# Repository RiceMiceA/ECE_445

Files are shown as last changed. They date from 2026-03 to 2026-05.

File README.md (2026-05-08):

# NuChef<sup>TM</sup> - AI Culinary Assistant

## Table of Contents
1. [Final Product](#1-final-product)
    - [Photos](#photos)
    - [YouTube Demo](#youtube-demo)
2. [How to use our repo?](#2-how-to-use-our-repo)
    - [Init](#21-init)
    - [Managing the submodule Unity folder](#22-managing-the-submodule-unity-folder)
    - [Network Configuration](#3-network-configuration)
    - [Troubleshooting](#4-troubleshooting)
5. [Third-Party Libraries & Licenses](#5-third-party-libraries--licenses)

## 1. Final Product
### Photos
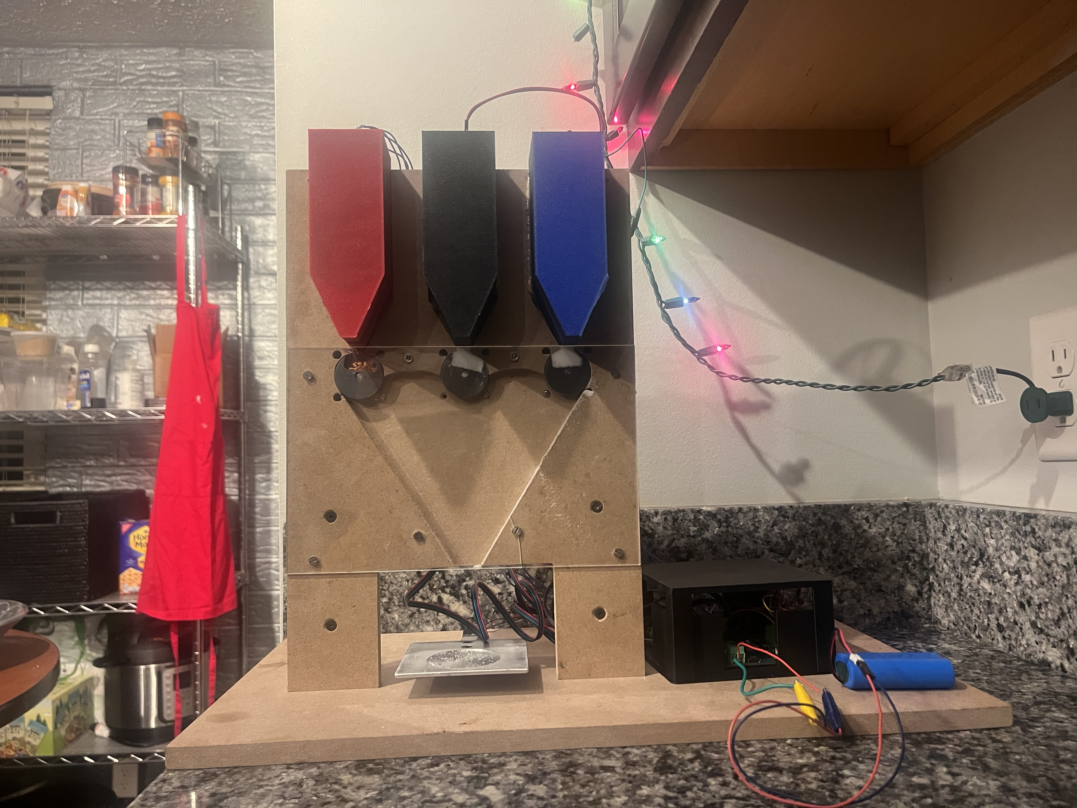
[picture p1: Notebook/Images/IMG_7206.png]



### YouTube Demo
NuChef Demo (https://www.youtube.com/watch?v=w1jBzbUWaAI)

## 2. How to use our repo?

### 2.1 Init
#### Freshly Clone 1st time
```bash
git clone --recurse-submodules <repo-url>
```

This does everything:
- clones the parent repo
- initializes submodules
- checks out the correct commits

#### Already cloned repo
```bash
git submodule update --init --recursive
```

### 2.2 Managing the submodule Unity folder
#### 2.2.1 Before Work/Update
#### In parent folder
```bash
git pull
git submodule update --init --recursive
```

#### 2.2.2 Post-work
```bash
cd path/to/submodule
git checkout main
git pull origin main
git add .
git commit -m "Update submodule"
git push origin main

cd /path/to/parent-repo
git add Software/src/Unity-PassthroughCameraApiSamples
git commit -m "Bump submodule"
git push origin main
```

### Verify Health
```bash
git submodule status
```

### Tip
```bash
git config --global submodule.recurse true
# if we wanna track the specific branch
git submodule set-branch --branch tony Software/src/Unity-PassthroughCameraApiSamples
git submodule update --remote
```

## 3. Network Configuration

### Kill previous run
```bash
kill $(lsof -t -i:8000) 
```

### Update IP Address before operation
```bash
Check the current ip address: 
```
When switching networks, update the backend IP (`192.168.x.x`) in these files:

| File | Line | Variable |
| --- | ---- | --- |
| [`Software/src/Unity-PassthroughCameraApiSamples/Assets/PassthroughCameraApiSamples/MultiObjectDetection/DetectionManager/Scripts/BackendClient.cs`](Software/src/Unity-PassthroughCameraApiSamples/Assets/PassthroughCameraApiSamples/MultiObjectDetection/DetectionManager/Scripts/BackendClient.cs#L19) | 19 | `m_baseUrl` |
| [`Software/src/web_app/main/script.js`](Software/src/web_app/main/script.js#L6) | 6 | `BACKEND_URL` |

> **Note:** The ESP32 now communicates via **BLE** (not WiFi), so it no longer needs an IP address or network config.

Then start the backend and BLE bridge:
```bash
# Terminal 1 — backend
cd Software/src/web_app
source .env   # loads OPENAI_API_KEY, OPENAI_MODEL, USE_LLM_PLANNER from .env file
uvicorn backend:app --host 0.0.0.0 --port 8000 --reload

# Terminal 2 — BLE bridge (connects to ESP32 over Bluetooth, forwards to backend)
pip install bleak httpx   # first time only
python ble_bridge.py
```

## 4. Troubleshooting

### Upload new ESP32 file
```bash
~/.platformio/penv/bin/pio run 2>&1 | tail -20
```

### ESP32 BLE not broadcasting / bridge can't find device
1. **Press the physical RESET button** on the ESP32-S3 board. It will re-advertise as `NuChef-Dispenser` within a few seconds.
2. If the bridge still can't find it, kill and restart `ble_bridge.py`. Linux's BlueZ stack sometimes caches stale BLE data.
3. As a last resort, power-cycle the ESP32 (unplug & replug USB).

### Serial port changed (`/dev/ttyACM0` ↔ `/dev/ttyACM1`)
After a reset or replug the port may shift. Check with:
```bash
ls /dev/ttyACM*
```
Then update `upload_port` and `monitor_port` in `Software/src/esp_driver/platformio.ini` if you need to re-flash.

### Permission denied on `/dev/ttyACM*`
```bash
sudo usermod -aG dialout $USER
# then log out & back in (or reboot) for the group to take effect
```

### Bridge connects but dispense doesn't trigger from the UI
- Make sure the backend (`uvicorn`) **and** `ble_bridge.py` are both running.
- Verify `BACKEND_URL` in `script.js` is `window.location.origin` (not a hardcoded IP).
- Check the bridge terminal for `BLE CMD →` and `write OK` logs when you click **Dispense**.

### Quick sanity check (motor spin from CLI)
```bash
# Direct BLE test — bypasses the backend entirely
python3 -c "
import asyncio
from bleak import BleakClient, BleakScanner
SVC  = '4e7a9b1c-d203-4e2a-b8f1-67c1d9e3f5a0'
CMD  = '4e7a9b1c-d203-4e2a-b8f1-67c1d9e3f5a1'
async def test():
    dev = await BleakScanner.find_device_by_name('NuChef-Dispenser', timeout=10)
    async with BleakClient(dev) as c:
        await c.write_gatt_char(CMD, b'spin', response=True)
        await asyncio.sleep(5)
        await c.write_gatt_char(CMD, b'stop', response=True)
asyncio.run(test())
"
```

## 5. Third-Party Libraries & Licenses

### Unity Utility Packages (MIT)
- **Repository:** https://github.com/meta-quest/Unity-UtilityPackages
- **Author:** Meta Platforms, Inc. and affiliates
- **License:** MIT License

> Meta Quest, "Unity-UtilityPackages," GitHub. [Online]. Available: https://github.com/meta-quest/Unity-UtilityPackages. [Accessed: May 7, 2026].

MIT License attribution:
```
Unity Utility Packages
Copyright (c) Meta Platforms, Inc. and affiliates.
Licensed under the MIT License.
https://github.com/meta-quest/Unity-UtilityPackages
```

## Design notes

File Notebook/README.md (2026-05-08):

# General Information about our ECE445 NuChef AI Culinary Assistant

## Problem

The processed food industry has become increasingly toxic due to chemical flavor additives, which have been associated with a 12%–32% higher cancer risk. At the same time, getting into cooking can be intimidating for new chefs. As a result, students and working professionals may rely on convenient but unhealthy meals.

Most currently available smart-cooking tools do not provide a real-time experience that guides users through the complete process from raw ingredients to the finished dish. This makes it difficult for users to learn how to cook or even get started. It is also inefficient to design recipes that adapt to the ingredients the user already has available, since a prospective cook would otherwise need to manually catalog everything on hand.

This creates two main problems: users may waste food, and recipe creation remains an expert skill that is difficult to customize. Spices are especially difficult to measure and control in a dish, even though they are often the most important contributors to flavor. A healthy and delicious diet is important for productivity and long-term health, but it can be difficult to accomplish consistently.

## Solution

We propose an **AI-Nutritious Culinary Assistant** that recognizes available ingredients and generates a personalized recipe with interactive, step-by-step guidance.

The system uses the **Meta Quest 3** as the user interface and sensor front-end. The headset streams video and voice commands to an edge vision processor running an ingredient-recognition pipeline. In addition to vision, the device integrates an environmental sensor module that measures ingredient weight for portion verification.

The appliance also includes a circular seasoning dispenser driven by stepper motors for proportional seasoning action. This enables closed-loop “dispense to target grams” assistance during cooking. The spice containers also contain IR sensors, allowing users to view the percentage of each spice remaining and receive an alert when a spice is running low.

## Visual Aid

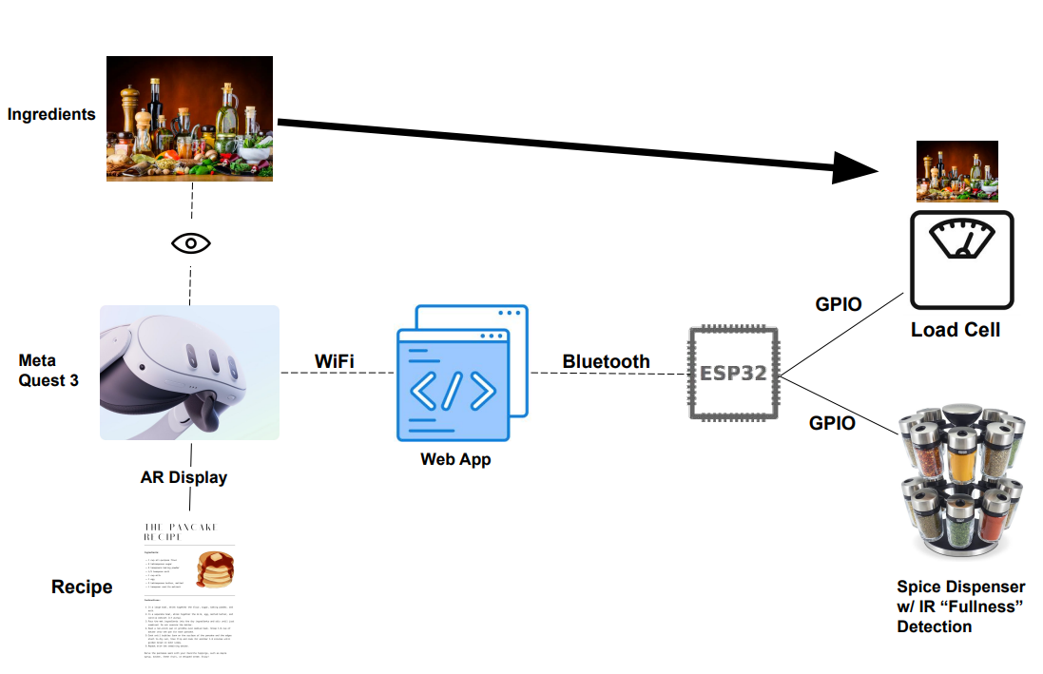
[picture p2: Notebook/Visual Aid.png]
High Level Abstraction of The Project Pipeline

**Figure 1. High-Level Abstraction of the Project Pipeline**

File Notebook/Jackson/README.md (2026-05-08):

# Engineering Logbook

---

## Date: 2/10/26

### Objective
Parts purchasing for our project

### Details
The first major milestone for our project is deciding on the parts to buy. After meeting with my group and discussing parts, we have landed on the following components:

- ESP-32 S3 WROOM
- 10g load cell with HX711 ADC module
- 17HE15-1504 stepper motors
- VL53L4CD IR ToF sensors

The PCB and battery components will be decided by Griffin, who has the most experience in PCB design.

In addition to ordering these components, we also need the Oculus headset borrowed from the library or from Professor Gruev’s lab to run our computer vision model.

---

## Date: 2/15/26 – 2/17/26

### Objective
Begin setting up environment and learning to use PlatformIO in preparation to begin coding ESP

### Details
Parts have arrived and we have given them to the woodshop with our general idea and concept of a design. Once they have finished the frame for the spice dispenser, I will be able to begin programming the motors.

Until then, I learned how to set up my PlatformIO environment in VSCode to be able to program the ESP. I originally looked at the Arduino IDE, but PlatformIO worked better with VSCode and members of my group had more knowledge using it.

I followed this tutorial to get my environment set up:

<https://randomnerdtutorials.com/vs-code-platformio-ide-esp32-esp8266-arduino/>

---

## Date: 3/2/26

### Objective
To get the motors connected to the ESP and ensure that they can spin and properly be controlled.

### Details
The main frame has returned from the supply shop and I am able to start work coding the motors and the sensors. The physical rotation of the motors is the most essential part of the project, so I am starting with this first.

We ordered a TB6612FNG motor driver breakout board to be able to easily control our stepper motors. We also have an older ESP-32 with breadboard pins that can be used and coded on the breadboard.

The motors were chosen due to their precision, as 200 steps result in one full rotation back to the starting position with generally specific accuracy.

The motors have four wires — `A+`, `A-`, `B+`, and `B-` — as seen in this datasheet:

<https://www.artme-3d.de/wp-content/uploads/2024/03/17HE15-1504S.pdf>

These four lines create two coils that allow for a spinning magnetic field when current is alternated through them in different directions. This is how we are able to get rotation in the stepper motors.

The DRV8833 is able to abstract this pin control into two pins, `IN1` and `IN2`, as seen in this datasheet:

<https://cdn.sparkfun.com/assets/0/1/b/b/3/TB6612FNG.pdf>

We are able to wire PWM and STBY to high and connect IN1 and IN2 to two GPIO pins on the ESP. We can then use the `AccelStepper` library to abstract the coding of these pins, though we understand that the current must alternate between the four pins to get a complete rotation.

The `AccelStepper` library examples can be found here:

<https://registry.platformio.org/libraries/waspinator/AccelStepper/examples>

Using a very basic example and modifying the code slightly, we can get one rotation on the motor each time we reset the ESP.

### Motor Test Code

```cpp
#include <Arduino.h>
#include <AccelStepper.h>
#include <BluetoothSerial.h>

BluetoothSerial SerialBT;

#define AIN1R 32
#define AIN2R 14
#define BIN1R 15
#define BIN2R 33

#define AIN1M 13
#define AIN2M 12
#define BIN1M 21
#define BIN2M 27

AccelStepper stepperRight(
    AccelStepper::FULL4WIRE,
    AIN1R, AIN2R, BIN1R, BIN2R
);

AccelStepper stepperMiddle(
    AccelStepper::FULL4WIRE,
    AIN1M, AIN2M, BIN1M, BIN2M
);

void spinMotor() {
    Serial.println("Spin command received");

    stepperRight.setCurrentPosition(0);
    stepperRight.moveTo(200);

    stepperMiddle.setCurrentPosition(0);
    stepperMiddle.moveTo(200);
}

void setup()
{
    Serial.begin(115200);

    // Stepper Motors Setup
    stepperMiddle.setMaxSpeed(800);
    stepperMiddle.setAcceleration(200);

    stepperRight.setMaxSpeed(800);
    stepperRight.setAcceleration(200);
}

void loop()
{
    stepperRight.run();
    stepperMiddle.run();
}
```

The general idea is to set the speed and acceleration of the motors and then tell them to move to position `200`. This means taking 200 steps, which for our motors is one full rotation.

There are only two motors set up here because the ESP we are using on the breadboard has limited GPIO. We will be testing this code at a future date.

---

## Date: 3/8/26

### Objective
To get the motors hooked up on the breadboard and use the ESP code to spin them on command.

### Details
We spent a lot of time on this day figuring out our communication with the ESP. We had to try multiple different cables until we found one that connected properly to my laptop.

We also found that, on this specific ESP that we were using for breadboard testing, certain pins that we thought were GPIO (like GPIO 4) caused problems when trying to program the ESP. It would not accept code over USB when those pins were used. These pins are likely related to resetting or idling the ESP, so we avoided them as much as possible.

We also realized that our TB6612FNG breakout board was made for general DC motors, not specifically stepper motors. It was still able to work, but stepper motors require a constant current to hold their position even when they are not actively rotating. This resulted in the chips getting very hot, so we could not leave them plugged in for too long.

Regardless, we were able to hook up the motors (two at a time because of limited GPIO on the ESP) and get them spinning.

We ordered a DRV8833 breakout board, which is the chip we are actually using on our PCB.

---

## Date: 3/9/26

### Objective
To get the project more prepared for the breadboard demo. This includes building a basic backend and frontend web app to allow the ESP to be controlled with the laptop.

### Details
The first step in setting up a web app was deciding how to build it. I decided to use FastAPI, as I do not need much bandwidth and it is easy to learn and test. I used this in conjunction with Uvicorn to get my server running.

I used GET and POST endpoints to allow me to see internal data as well as communicate with the ESP. The frontend/backend code can be seen in the GitHub commit labeled **WiFi capabilities**.

### ESP WiFi Connectivity Code

```cpp
WebServer server(80);

const char* ssid = "Triangle";
const char* password = "houserules";

void connectWiFi() {
  WiFi.begin(ssid, password);

  Serial.print("Connecting");

  while (WiFi.status() != WL_CONNECTED) {
    delay(500);
    Serial.print(".");
  }

  Serial.println("");
  Serial.print("ESP32 IP: ");
  Serial.println(WiFi.localIP());
}

void loop()
{
  stepper.run();
  server.handleClient();
  stepperMiddle.run();
}
```

With this code, the ESP is able to listen over WiFi. The web app can then call the `spinMotor()` function, which results in the spices being dispensed.

The SSID and password need to be changed based on location. In this example, it is configured for my home network.

This is a basic but effective way to communicate with the ESP over WiFi, and we confirmed it with a simple web app that can spin the motors.

### Demo API Endpoints

| Name | Type | Description |
|---|---|---|
| `new_recipe` | POST | Used by the Meta Quest 3 to send the selected recipe JSON |
| `status_update` | POST | Used by the ESP32 to send IR sensor and load cell data |
| `set_containers` | POST | Used by the frontend to allow user configuration of spices |
| `container_info` | GET | Used by the frontend to get IR sensor readings and load cell readings |

### Additional Backend GET Endpoints

| Name | Type | Description |
|---|---|---|
| `get_status` | GET | Returns the entire system state |
| `get_spices` | GET | Extracts and returns spices from the recipe JSON |
| `get_spice_dispense` | GET | Returns only spices currently in the dispenser |
| `get_container_info` | GET | Returns information on all containers |

### Basic Frontend

The frontend has some basic configuration that will later be used to connect the Oculus-to-ESP pipeline.

The “Spin Motor” button is the most important part of the demo because it shows we can communicate with the ESP over WiFi and control the motors remotely.

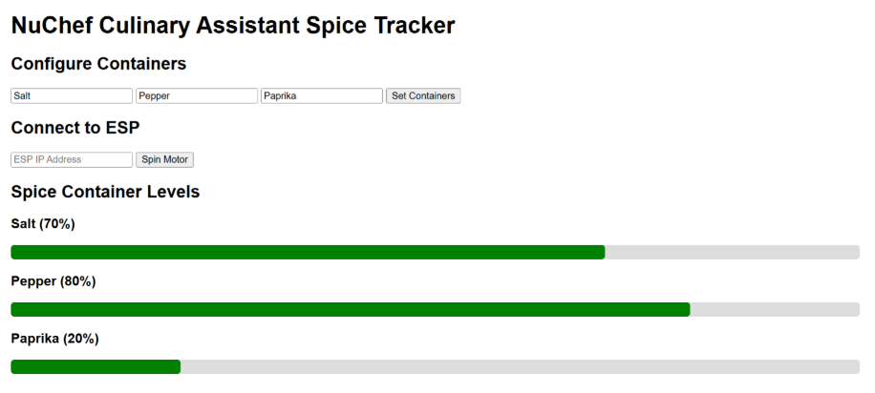
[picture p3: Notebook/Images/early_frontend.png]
Early Frontend


---

## Date: 3/10/26

### Objective
To debrief the breadboard demo and discuss next steps.

### Details
At the breadboard demo, the ESP was having trouble connecting to the university WiFi. It also was not able to connect to my phone’s hotspot.

We completed the demo using physical buttons to show some functionality, but afterward we discussed how to resolve the networking issues.

We decided to switch the ESP communication method from WiFi to Bluetooth. Griffin has worked with ESP Bluetooth before and said it is relatively simple and reliable. This will be our plan moving forward.

---

## Date: 3/28/26

### Objective
To hook up the load cell on the breadboard and get it running before our progress demo.

### Details
The load cell amplifier that came with the load cell was not working; it seemed like the chip was faulty. We ordered new HX711 breakout boards that would arrive before the progress demo, although we had to pay extra for shipping.

While waiting for the load cell amplifiers to arrive, I began work on the ESP code for them.

The load cell has four wires coming out of it. These wires allow us to provide an input voltage and read the voltage across the resistance terminals within the load cell.

When tension is applied to the cell, the resistance values change slightly, which causes a change in the internal voltage and allows us to read the weight. We can see this in the diagram below:

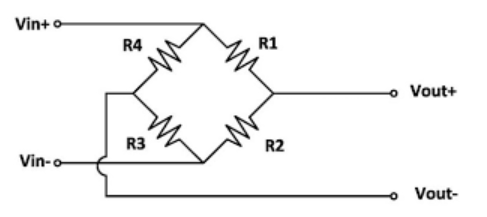
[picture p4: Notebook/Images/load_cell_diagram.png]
Load Cell Diagram


The HX711 amplifier allows us to amplify this small voltage change into an actual reading. We can then use GPIO and the HX711 library to get weight readings.

### HX711 Test Code

```cpp
#include "HX711.h"

// HX711 circuit wiring
const int LOADCELL_DOUT_PIN = 19;
const int LOADCELL_SCK_PIN = 20;

HX711 scale;

void setup() {
  Serial.begin(115200);

  pinMode(LOADCELL_SCK_PIN, OUTPUT);
  digitalWrite(LOADCELL_SCK_PIN, LOW);

  scale.begin(LOADCELL_DOUT_PIN, LOADCELL_SCK_PIN);
  scale.tare();
  scale.set_scale((1250.0)/1.0); //(reading)/actual weight
}

void loop() {

  if (scale.is_ready()) {
    float reading = scale.get_units(50);

    if(abs(reading) <= 0.05){
        reading = 0.00;
    }

    Serial.print("HX711 reading: ");
    Serial.println(reading);

  } else {
    Serial.println("HX711 not found.");
  }

  delay(1000);
}
```

---

## Date: 4/5/26

### Objective
To get the load cell working and hook up both the load cell and the motors for the progress demo.

### Details
The motors were simple to hook up because they used the same wiring as before, but now with our new breakout boards using the correct chips.

For the load cell and HX711, the wiring was also relatively straightforward:

- Red → `E+`
- Black → `E-`
- Green → `A+`
- White → `A-`

Once these are connected to the HX711, we only need the `DATA` and `SCK` lines connected to the ESP.

- `SCK` controls the clock
- `DATA` is used to read the data

Using the code written previously, I was able to display readings on the serial monitor.

I placed a 1-gram weight on the scale, which produced a reading of `1250`. I used this value to calibrate the scale so readings would display in grams.

There is some noise on the load cell because it is a low-weight cell and therefore very sensitive to changes in current or voltage, including outside electrical noise.

To combat this, we poll many data points and average them before displaying a reading. This increases the time between readings, but the results are much closer to the expected value.

Tony had made a slightly more advanced web application, so I gave him the load cell code so he could quickly implement it before the progress demo.

---

## Date: 4/7/26

### Objective
Progress demo and part pickup

### Details
Our progress demo went very well.

I also received many parts from Aniket that we had ordered through the ECEB supply shop. These included many of the top-solder components for our PCB, such as:

- Capacitors
- Resistors
- ESP module
- Voltage regulator

The remaining parts are still arriving in the mail, but we are close to having everything needed to begin soldering.

---

## Date: 4/12/26

### Objective
To begin soldering

### Details
I met with the rest of the group and we learned from a friend how to use solder paste and the heat plate at Triangle to top-solder our board.

Things were going well, but the voltage regulator chip developed a large solder bridge. While trying to separate the pins, one of them broke off.

We decided to order a replacement with express shipping and wait for it to arrive before continuing.

---

## Date: 4/22/26

### Objective
To get the IR sensors connected to the system and working.

### Details
Griffin soldered a small PCB with the IR sensor for testing on the breadboard.

The issue is that the IR sensor we bought has contacts underneath the chip, making it difficult to tell whether any contacts are disconnected or bridged.

I tried hooking the chip up to the ESP. On the VL53L4CD sensor, the two primary GPIO-related lines are:

- `SCL` — clock
- `SDA` — data

I could not get any readings from the sensor, even after trying different GPIO pins, wires, and configurations.

We decided to stop using the hand-soldered IR sensors and instead purchased VL53L4CD breakout boards.

---

## Date: 4/25/26

### Objective
To hook up the new IR sensor breakout boards and get readings displayed on the serial monitor.

### Details
I used the new breakout boards on the breadboard to try to get readings from the IR sensors.

The code I used was the basic continuous example from the Adafruit VL53L0X library:

<https://registry.platformio.org/libraries/adafruit/Adafruit_VL53L0X/examples/vl53l0x_continuous/vl53l0x_continuous.ino>

I spent a lot of time moving wires around because I believed there was a problem with my pin assignments or wiring.

While working, I accidentally pulled one of the wires out of the load cell. This took a long time to repair because the wires had been glued in place by the ECEB wood shop.

In the end, I did not make much progress, but we discovered that we had a spare load cell available and swapped it into the project.

---

## Date: 4/27/26

### Objective
To get all of the load cells hooked up and working.

### Details
We spent time hooking the IR sensors to the breadboard and ensuring that the pin assignments were correct.

Eventually, using the basic code, we were able to get readings that appeared accurate. However, when the sensors were placed on our spice containers, the calculated percentages based on distance readings were incorrect.

We were not able to fully resolve the issue before the demo, but we ensured the rest of the project was ready for the final demonstration.

Everything else was functioning properly.

---

## Date: 4/28/26

### Objective
Rig up the new containers and IR sensors

### Details
Tony and Griffin spent time the previous day diagnosing the IR sensor issue. They realized that the sensors use a cone-shaped transmission pattern that was reflecting off the walls of our containers.

In short, the containers were too small and interfered with the IR sensor readings.

Griffin designed and 3D printed new containers.

Tony and I spent time replacing the plexiglass, which required:

- Drilling new screw holes in the wooden frame
- Installing a new sheet of plastic

We also glued the new spice containers in place and left them to dry overnight.

The next day we planned to attach the IR sensors to the tops of the containers and test them.

---

## Date: 4/29/26

### Objective
Ensure functionality of the IR sensors, test the full system, and take R&V data.

### Details
We were able to connect the IR sensors and observed far less interference from the walls of the new containers.

This produced much more accurate readings.

I attended another team meeting and left Tony and Griffin to finish collecting R&V data.

---

## Date: 5/4/26

### Objective
Present our project at the awards ceremony demo.

### Details
We presented our completed project at the awards ceremony in the ECEB.

We are very happy and proud of how the project turned out.

---

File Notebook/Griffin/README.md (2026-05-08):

Final Product

In The Workshop

Febuary 4th

Objective: Figure out the physical design of what we want to make, and whether we want to use the machine shop.
Record of what was done: We discussed the physical design for a while. We discussed different ways of making a lazy susan design. Options include rotating the spice dispenser using ball berrings and a central motor, or rotating the cup to be dispensed to to the spice dispensers themselves. Pros of rotating the spice containers include increased visual appeal, less total motors, and simpler fittings for aligning spices (only need one funnel/dispensing shoot). Pros of rotating the cup include ease of design and less moving parts.

Furthermore, we discussed how we would actually dispense the spice. We discussed ideas of using gears to create linear motion, or some sort of rotating wheel with a pass through that would allow spice to go through when lined up.

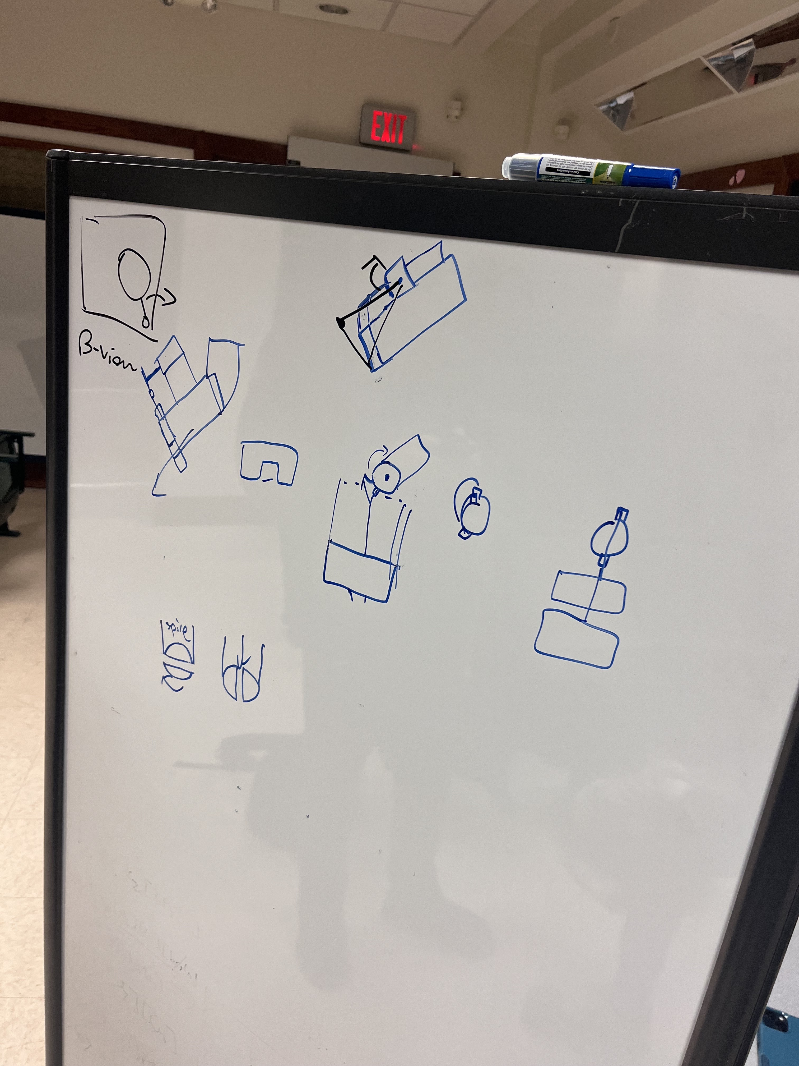
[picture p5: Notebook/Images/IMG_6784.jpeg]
Whiteboard


Febuary 5th

Objective: Meet with Greg/Machine Shop about ideas.
Record of what was done: Greg brought up the point that we really do not need to rotate anything. Everything can just be dispensed from their own containers into a central funnel. The downside of this is each spice container needs its own motor, increasing cost. Therefore, we settled on just 3 spices as essentially a proof of concept. Scaling does not increase the design complexity much. Can be made as soon as we supply motors.

Febuary 9th

Objective: Discuss additional hardware complexity.
Record of what was done: Settled on adding IR sensor for spice level detection. Two options for this. One, smoke detector style break beam detector. Two, IR time of flight sensor. Decided on IR Time of Flight for higher precision vs the digital high/low supplied by break beam style. Drew this image to explain how it worked to my groupmates.

IR_Diagram

Febuary 11th

Objective: Put in myece order request for load cells and motors.
Record: Ordered these parts from Amazon through my.ece
Load Cell
https://www.amazon.com/Wishiot-Precision-Miniature-Electronic-Portable/dp/B0C3QHT4TT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

Stepper Motors
https://www.amazon.com/STEPPERONLINE-Stepper-Bipolar-42x42x38mm-Connector/dp/B0B38GHRH8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

Load cell is a 1kg load cell. Plenty large enough for the amount of spice we intend to measure, along with most smaller ingredients, while still providing enough precision for smaller amounts of strong spices.
Stepper motors are 1.5A, which on on edge of typical rated discharge current for lithium ion batteries. Will need to be careful in designing around this and to only run one motor at a time.

Febuary 17th

Objective: Take delivery of parts
Record: Took delivery of load cell and stepper motors. Delivered to Machine Shop. First order put in and should be done by end of week or early next week.

Febuary 20th

Objective: Start PCB schematic work.
Record of what was done: Have past PCB design experience, able to copy over microcontroller schematic, usbc port schematic, and voltage regulation schematic from prior project. AP2112 linear dropuot regulators a fine choice. Dropout will likely not be a problem as sensors are low current. Will need to figure out how to run higher current motors. Perhaps seperate battery pack. Will need to migrate ESP32 C3-Mini to ESP32 S3-Wroom for more GPIO pins though. Would have liked to reuse battery charging module, but the previously used MCP73871 looks hard to hand solder. Will need to look for an easier to solder version, perhaps in an SOT format. Attached are the copied schematics.

Microcontroller
Voltage_Regulator
USB C

Febuary 24th

Objective: Finish Schematic
Record of what was done. Made rest of schematic decisions. Found MCP73831 battery charger unit. Major drawbacks from MCP73871 include inability to power system from USB and much smaller max charging speed. Huge benefit is SOT-23 format instead of QFN format with hidden pins. Good option for this type of project. 

Found DRV8833 motor drivers. Not technically a stepper motor driver, but rather dual H-Bridge, but capable of driving stepper motor at low voltages. This works here, as motors will be driven by 3.7V Lithium Ion battery.

Downsides of DRV8833 that are not relevent here
-Heats up more during continuous use (We will disable drivers when not in use)
-Can't handle higher voltages (We only have 3.7V available)
-Less Smooth/Precise (We only need to be able to do 180 degree rotations, so this lower precisions should not be an issue)

Benefit is simpler implementation and smaller footprint.

For load cell, HX711 differential analog to digital converter is used. This comes with load cells, but for integration (and class) purposes, we will build into our PCB. Used simpler wiring method that does not use the internal regulated analog supply. Our power rail should not be too noisy, and there are plenty of decoupling capacitors, and relatively low load demands on it, so this should be sufficient for getting resonably accurate readings. We won't be using the motor and load cell at the same time anyways, which would be the only thing that could pull the power supply low.

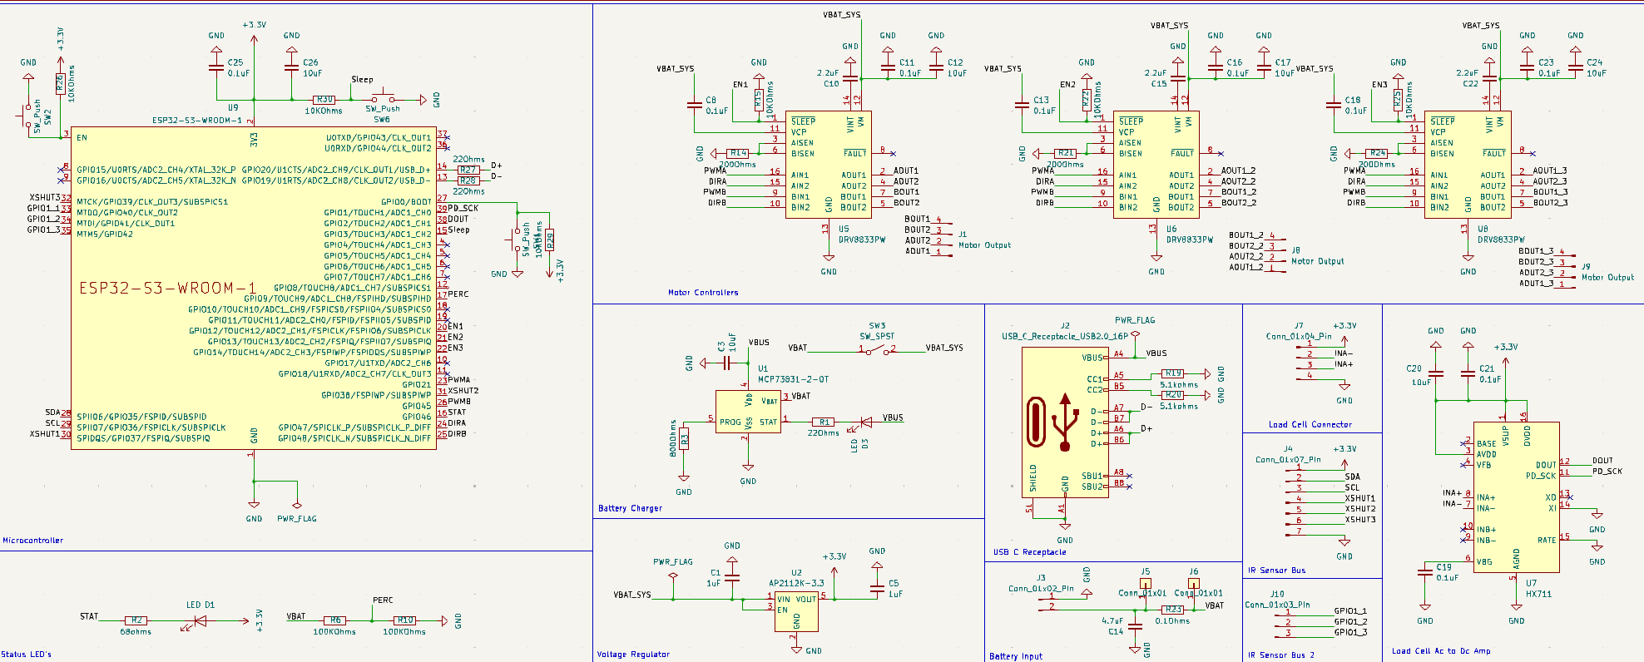
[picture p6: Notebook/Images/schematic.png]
Schematic


March 3rd

Objective: Routing
Record: Assigned footprints, routed full board. Settled on 0805 resistors and capacitors as a good balance between size and solderability. Found these cool screw hole terminals for all the wires from Pheonix Connect. Useful because we can remove and insert wires without soldering, which will be nice for testing. Went with max size of 100x100 mm just for ease. Included mounting holes. Did via stitching for the first time.

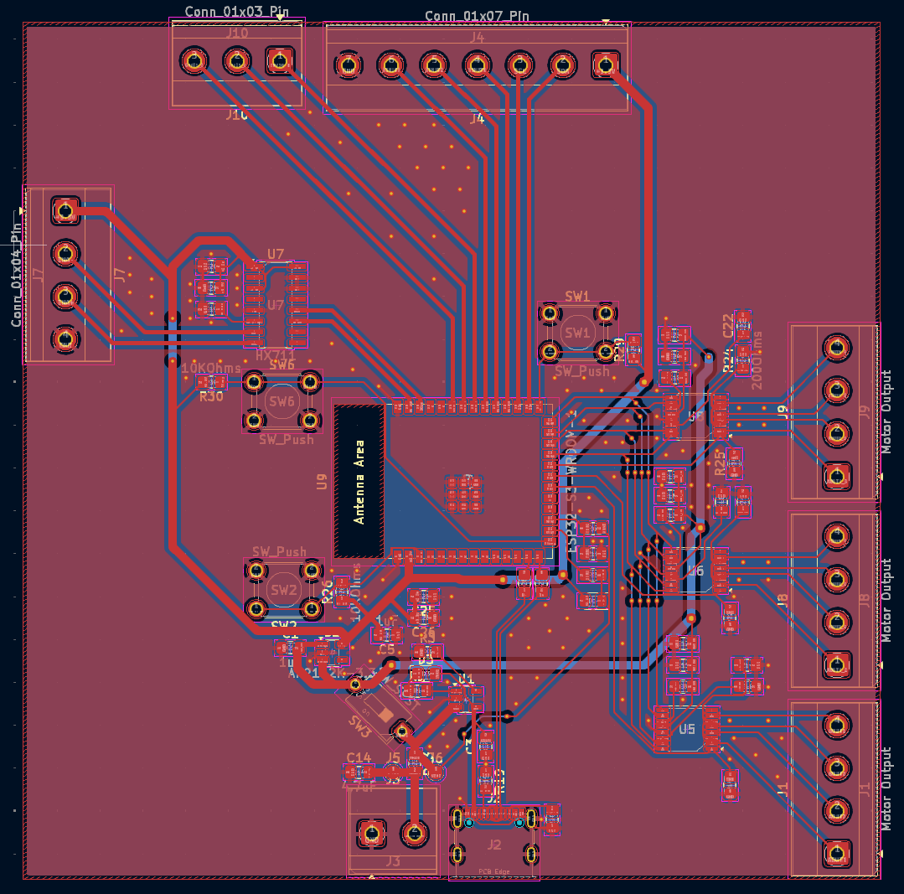
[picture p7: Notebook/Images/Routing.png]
Routing


March 8th

Objective: Control stepper motor with microcontroller for breadboard demo
Record of what was done: We spent the first couple hours trying to communicate with an old ESP32 Wroom breakout module I had. We tried a bunch of things including putting the board in boot mode, powering it from a digital power supply, from battery, probing all the power lines, probing the breadboard for shorts, etc. Turns out our USB micro cable was broken. We swapped to a new cable and were able to communicate. We then wired a motor driver we got off Amazon. Turns out the part we got (TB6612FNG) was just two H bridges for DC motors, and was not designed for continuous current, and was burning up really quick, so we had to keep unplugging it. Still, we were able to spin our motors for the first time. 

We ordered some breakout boards for the actual parts we will use on the PCB, including a DRV8833 breakout board and an ESP32 S3 Wroom breakout board. That way we can verify everything will work for the final board.

March 12th

Objective: Submit PCB order for round 3
Record: Submitted order Thursday evening but was still able to be included in PCB round 3 order. 

March 28th

Objective: Get Load Cell working
Record: Amplifier which came with load cell was broken. Ordered a new HX711 breakout board. Also placed order for all of the PCB parts. Some were in stock with the school, some were ordered through digikey. HX711 was out of stock a lot of places for some reason so had to order through LCSC which cost a lot in shipping. PCBs came in this day as well.

April 5th

Objective: Get load cell working and motors driven by new driver.
Record: Easy swap to new motor drivers. Worked right away. Jackson got load cell working after I left.

Motor Driver Breadboard
Load Cell Breadboard

April 12th

Objective: Start soldering
Record: Started well. Got microcontroller on. Pivoted to power circuitry. Put on two SOT-23 parts in battery charger and voltage regulator. Ended up with large bridge on voltage regulator. Accidently broke a pin off trying to remove bridge. We only had one of these chips so had to rush order new ones to put on. Nothing else to test until new chips come in as need regulated voltage for whole system.

April 14th

Objective: Get Power
Record: Put new voltage regulator on. No power. Do a lot of probing that reveals issue. First checked resistance between 3.3V net and ground, and it is resonably high, so there is no short. Then checked resistance between pins of voltage regulator and also found no short. Seems issue was again that I had broken a pin or in some way damaged the voltage regulator. Fix is to put a new voltage regulator on. Accidently ripped USB C port off, will need to put a new one on.

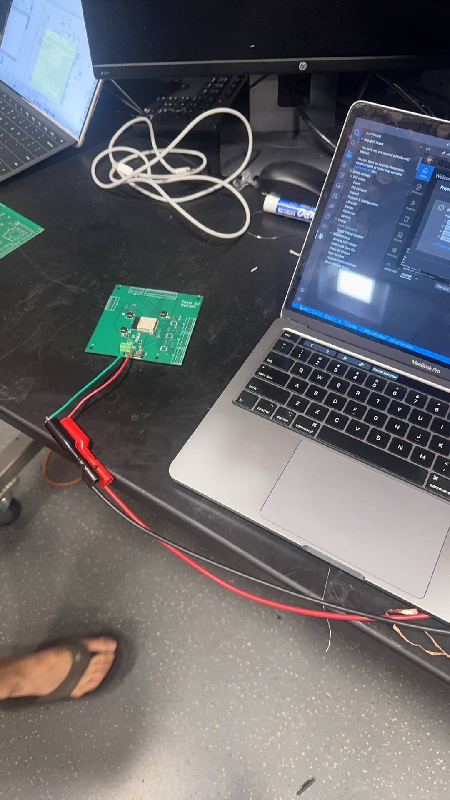
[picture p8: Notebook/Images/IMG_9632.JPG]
Testing Power


April 15th: Get Power
Record: Put new voltage regulator on and immediatly got 3.3V, which was good. Put on a new USB-C port on, along with the boot and reset buttons to try flashing. Powered up, put in boot mode, and was able to flash! Weirdly serial monitor was not working. I flashed simple hello world code, and nothing got printed to serial. Not sure where this issue came from as am able to flash fine, so clearly communication is working fine. Maybe just a code error. Not going to look into it right now. Soldered the rest of the board, but was too tired to rest anything.

First Time Flashing

April 18th

Objective: Test peripherals
Record: First time testing again have no power. This time I probe 3.3V and have an obvious short. Resistance is super low (like sub 1 ohm at places). Off initial visual inspection I guess the issue may be one or both of the LEDs, so I remove both, but this does not fix the issue. Then, using the micrometer, I identify the probe to be a short between pins on the HX711. I remove this and it fixes the short. 

After flashing the motor code, the motors will not run. Probing the motor controllers, I find that all of them have a short between all of the four input lines. This makes sense, as in the design, all 3 drivers share the same input lines, and the motor that is controlled is only toggled by each motor drivers sleep mode (awakening one motor driver at a time). By visual inspection (and by probing which has the lowest resistance), I was able to identify the middle motor driver as the cause of the short. After removing, other two motors are able to be controlled. Leave it at this for now.

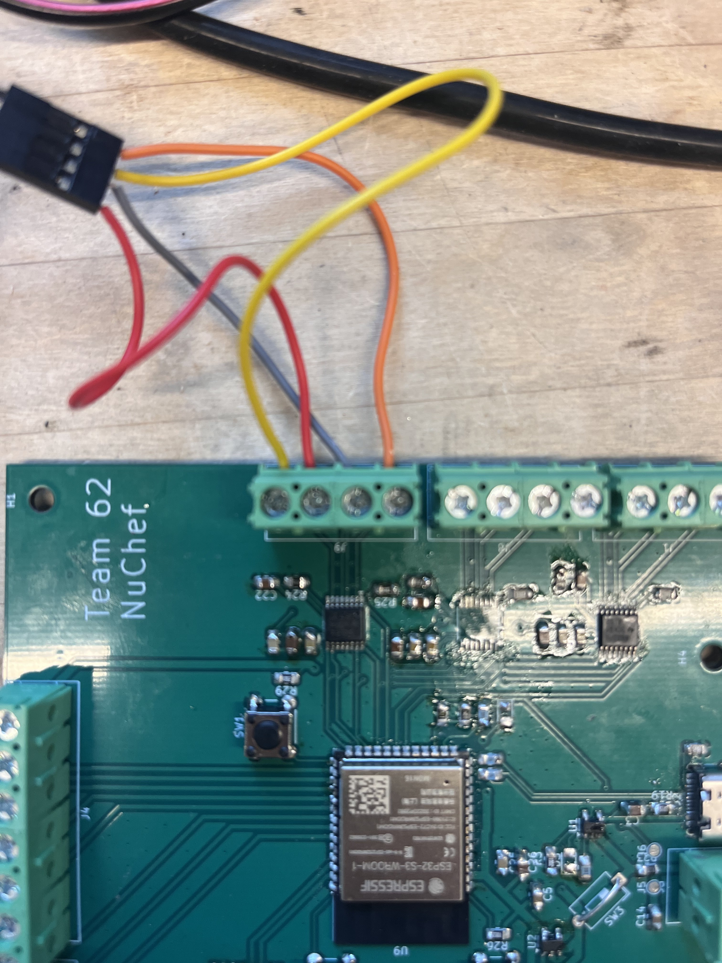
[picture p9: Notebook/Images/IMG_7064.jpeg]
Pre Testing


April 20th 

Objective: Put parts back on that I removed
Results: Soldered back on missing parts, did not check if they worked.

April 21st: Validate soldering
Results: All motors worked fine. Load Cell was weird to get working, as wires were hard to get good contact with, but got it going eventually.

April 24th

Objective: Figure out IR Sensors
Results: Unable to be communicated with. After some probing, find there are many shorts with the hidden pins of the IR sensor module. Abandon ship and order presoldered bare IR sensor.

April 27th

Objective: Get new IR sensors working
Results: After solder wires onto one of the modules, we get good readings in free space. That is, when testing it pointed at near objects such as the table, the readings given are pretty realistic. However, once put inside housing, readings are nonsense. Getting readings that increase in distacnce as spice level gets higher, vastly different readings for each of the 3 spice containers, and drifting calibration. Abandon for demo.

April 28th

Objective: Fix IR Sensor for final 10
Results: Identify IR Sensor issue is that IR cone is interacting with walls of containers before it interacts with spice. This was giving the nonsense readings. 3D print new spice containers that are larger than the cone width at bottom using 

cone diameter ≈ 2 × distance × tan(25° / 2)
=2 x 100mm * tan(12.5) = 44mm

So I made the container have 50mm square sides. This would ensure the IR sensor would only read the spice level. These printed over night.

Spice Container

April 29th

Objective: IR Sensor final testing
Results: After glueing on the IR sensors, we were able to calibrate using what we deemed to be fully filled and empty. We then ran all of our validation tests. For the IR sensors we found 1.6% error based off the mass percentage. We also did the motor spin test to find the drift and found it to be under 1% from intended full rotation. We validated the load cell comparing it to readings from a profesional scale and found the average error to  be under 1 gram. While we were doing this we were taking battery measurements and confirmed the battery was charging.

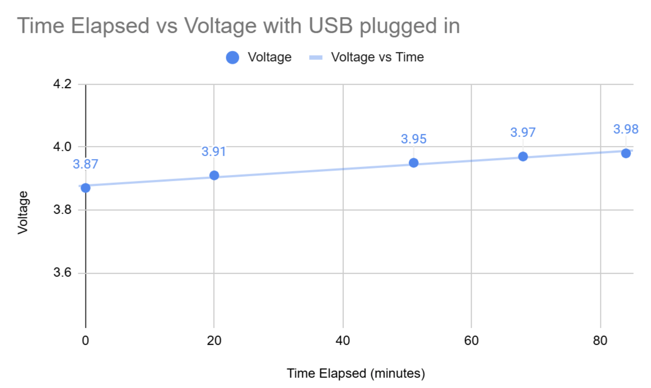
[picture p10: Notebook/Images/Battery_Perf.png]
Battery Percentage

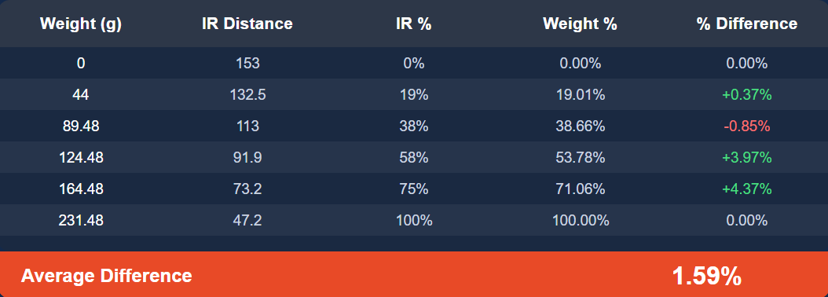
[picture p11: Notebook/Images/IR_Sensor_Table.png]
IR Sensor Table

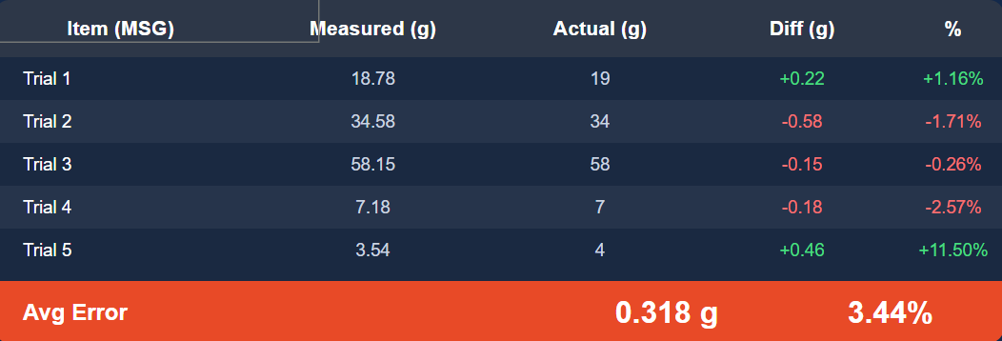
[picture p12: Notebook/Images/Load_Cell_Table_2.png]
Load Cell Table

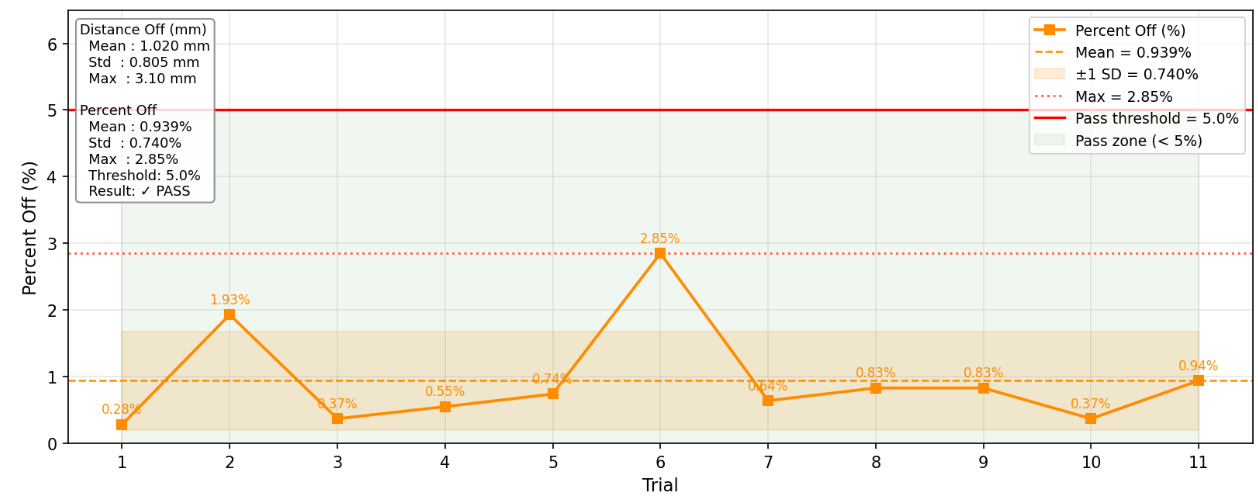
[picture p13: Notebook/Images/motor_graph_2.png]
Motor Graph


May 4th

Objective: Compete in Final 10
Results: Demoed our project to judges. Everything was still working. Did not win but honored to make final 10!

![Final}(../Images/IMG_9755.png)

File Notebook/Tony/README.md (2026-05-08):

# Tony's Lab Notebook
## Vision Subsystem Development

## Table of Contents
- [Apr. 27th](#apr-27th)
- [Apr. 26th](#apr-26th)
- [Mar. 28th](#mar-28th)
- [Feb. 15th](#feb-15th)
- [Jan. 25th](#jan-25th)
- [References](#references)

---

# Apr. 27th

### Bug Fix — Confirmed Ingredient List (`DetectionManager.cs`)
- **Root cause:** `ConfirmVisibleIngredients()` called `m_confirmedInstances.Clear()` on every A-press, wiping previously accumulated markers each time the user stamped a new spatial anchor.
- **Fix:** Removed the `ConfirmVisibleIngredients` call from the A-press block entirely. The A-press now only calls `SpawnCurrentDetectedObjects()`. Ingredients remain candidates until the user presses **X**, at which point `RebuildConfirmedFromMarkers(m_spawnedEntities)` promotes the full accumulated marker list to confirmed in one shot.
- The confirmed list is now the spatial marker list — it can never lose data between A-presses.

---

### Feature — Per-Instance Ingredient Weighing (full pipeline verified)
Confirmed the end-to-end flow correctly tracks and measures every physical instance of an ingredient:

1. **A-press (LiveScan)** — spawns a spatial marker for each bounding box not already covered; markers accumulate across multiple A-presses. Multiple eggs in different locations each get their own marker.
2. **X-press** — `RebuildConfirmedFromMarkers` iterates every marker with no deduplication, building e.g. `["egg", "egg", "egg", "garlic"]`.
3. **Y-press (IngredientReview phase)** — full list POSTed to `/ingredients_confirmed`; backend `_build_ingredient_instances` expands it into `egg_1 "egg 1/3"`, `egg_2 "egg 2/3"`, `egg_3 "egg 3/3"`, `garlic_1`.
4. **`/ingredient_review` polling** — steps through each instance individually; `all_complete` only becomes `true` when every single instance has a recorded weight.

---

### Feature — AR Spatial Cues During Weigh-In (`IngredientReviewManager.cs`)
Added highlight and arrow cues that point to the exact spatial marker being weighed as the user navigates between ingredient instances.

**New Inspector fields:**
- `DetectionManager m_detectionManager` — provides access to `SpawnedMarkers`.
- `GameObject m_highlightPrefab` — assign `HighlightCuePrefab`; spawned in pulse mode.
- `GameObject m_arrowPrefab` — assign `ArrowCuePrefab`; bounces above the target marker.

**New private state:** `m_activeHighlight`, `m_activeArrow` — destroyed and recreated on every index change.

**`ClearCues()`** — destroys active cue objects; called from `EndReview()` and before every `UpdateCues()` call.

**`UpdateCues()`** — called at the end of every `UpdateHud()`. Iterates `SpawnedMarkers`, filters by `current.label`, picks the Nth match using `instance_index - 1` (backend is 1-based), then instantiates the highlight (pulse) and arrow on that marker's transform. Uses `GetComponentInChildren` to support nested prefab hierarchies.

---

### Feature — Recipe Complete Hides HUD (`RecipeGuidanceManager.cs`)
Previously when `action == "complete"` arrived, `IsGuiding` was set to `false` but `ClearGuidance()` was never called, leaving the HUD panel and AR cues visible.

**Fix:** Added `m_cueRenderer?.ClearCues()` and `m_hudController?.Hide()` directly in the `action == "complete"` branch of `ApplyStep()`, consistent with what `ClearGuidance()` already does on external stops.

---

### Feature — Confirmed Ingredient Count Display (`web_app/main/`)

**`script.js`**
- Replaced plain `renderList("confirmed-list", ...)` with a new `renderConfirmedList()` function.
- Reads `ingredient_instances` (already present in `/state`) to display per-label counts and average measured weights: e.g. `egg ×3  58.2g avg`.
- Falls back to `confirmed_ingredients` (plain unique labels) before X is pressed.

**`style.css`**
- Added `.ing-count` — accent-blue pill badge showing `×N` for any label with more than one instance.
- Added `.ing-weight` — muted green text showing average measured weight once instances are weighed.

---

### Feature — Ingredient Count Context Sent to LLM (`backend.py`)
Strengthened the `RECIPE_PLANNER_INSTRUCTIONS` prompt with an explicit description of `ingredient_summary`:
- `count` = number of physical items the user detected and marked (e.g. `count=3` means 3 eggs).
- `total_weight_g` / `average_weight_g` to scale seasoning correctly.
- Instruction to mention count in `display_text` / `voice_text` for grab/move steps when `count > 1` (e.g. "Pick up all 3 eggs").

---

### Inspector Wiring Required (Unity Editor)
On the `IngredientReviewManager` component, assign:
- `m_detectionManager` → the scene `DetectionManager` GameObject
- `m_highlightPrefab` → `HighlightCuePrefab` from `DetectionManager/Prefabs/`
- `m_arrowPrefab` → `ArrowCuePrefab` from `DetectionManager/Prefabs/`

---

# Apr. 26th
### Backend — `Software/src/web_app/backend.py` (1238 lines, heavily expanded)

**LLM Recipe Planner (replaces mock placeholder)**
- `_generate_llm_recipe()` calls the OpenAI Responses API \[10\] with a strict JSON schema (`RECIPE_PLAN_SCHEMA`) and a `RECIPE_PLANNER_INSTRUCTIONS` system prompt.
- Pydantic models `RecipePlan`, `RecipeStep`, `DispenseSpec`, `SelectorTarget` validate LLM output before any state change.
- `_postprocess_recipe_plan()` normalizes + sanitizes the LLM result; falls back to mock on any failure.
- Controlled by env vars: `USE_LLM_PLANNER=1`, `OPENAI_API_KEY`, `OPENAI_MODEL`. Auto-loads a `.env` file.
- `system_state["last_planner_status"]` tracks whether LLM succeeded or fell back.

**Richer Step Schema**
- Every step now carries: `step_id` (unique hash), `render_plan` (focus + assist presets), `completion_mode` (`user_confirm` / `dispense_done` / `timer_done` / `auto`), and `targets` / `destination` (selector objects for AR cue resolution).
- `_compile_render_plan(step)` maps action types (`grab`, `season`, `move`, `mix`, `wait`, `complete`, etc.) to `focus_preset` + `assist_preset` pairs.
- `_resolve_default_completion_mode(action)` maps action → completion_mode automatically.
- `_build_step_status(step)` builds the enriched `/current_step` response including live dispense weight.
- `schema_version` field added to step payloads for forward compatibility.

**New Endpoints**
- `POST /vision_frame` — Quest posts structured YOLO frame (≤20 detections); updates candidate ingredients, frame count, receive timestamp.
- `POST /rv_event` — R&V latency probe; Quest sends `quest_send_ms`, backend computes end-to-end latency and updates p50/p95/max.
- `GET /rv_state` — Compact PASS/FAIL verification snapshot for the dashboard R&V panel.
- `POST /tare` — Zeroes the load cell reference weight in system_state.

**R&V Telemetry added to system_state**
- `last_vision_frame`, `vision_frame_count`, `vision_last_receive_ms`
- `rv_event_count`, `rv_duplicate_count`, `rv_latency_p50_ms`, `rv_latency_p95_ms`, `rv_latency_max_ms`

---

### ESP32 Firmware \[8\] — `Software/src/esp_driver/src/main.cpp` (complete rewrite to BLE)
- Was: WiFi HTTP polling loop (`HTTPClient`).
- Now: BLE GATT peripheral advertising as `"NuChef-Dispenser"` with a custom GATT service.
- Three GATT characteristics:
  - `CMD_CHAR` (Write) — receives dispense commands as JSON
  - `RSLT_CHAR` (Notify) — sends `command_result` JSON back
  - `WT_CHAR` (Notify) — sends periodic weight heartbeats
- Motor wiring changed to TB6612 + FULL4WIRE steppers \[11\]; all 3 motors share 4 coil-drive pins, selected by individual ENABLE lines.

---

### New File — `Software/src/web_app/ble_bridge.py`
- Async Python script (`bleak` + `httpx`) acting as BLE ↔ HTTP glue layer.
- Scans and connects to ESP32 peripheral by service UUID, with device-name fallback.
- Polls `GET /pending_command` every second; writes command JSON to `CMD_CHAR`.
- Subscribes to `RSLT_CHAR` and `WT_CHAR` notifications; forwards to `POST /command_result` and `POST /status_update`.
- Handles auto-reconnect on disconnect.

---

### New Unity Scripts (`DetectionManager/Scripts/`)

**RecipeGuidanceManager.cs**
- Polls `/current_step` at 0.3 s intervals; detects `step_id` changes to avoid redundant cue updates.
- Resolves target ingredient transforms via SceneObjectRegistry; hands step + targets to CueRenderer.
- Runs completion watchers: `WatchDispenseDone()`, `WatchTimerDone(duration_s)`, `WatchAutoAdvance()`.
- Exposes static `IsGuiding` bool that gates all DetectionManager input.
- `StopGuidance()` clears AR cues + hides HUD; does NOT reset backend recipe.

**RecipeStepPayload.cs**
- Full serializable data model for `/current_step` JSON: `schema_version`, `step_id`, `RenderPlan`, `SelectorTarget`, `StepStatus`, `completion_mode`, `targets`, `destination`.

**CueRenderer.cs**
- Spawns / repositions / destroys AR cue GameObjects from Inspector prefab slots.
- Maps `focus_preset` values (`soft_highlight`, `pulse_highlight`, `success_pulse`, `text_panel_only`) and `assist_preset` values (`ghost_hand_grab`, `arrow_to_target`, `ghost_hand_move`, `arrow_dispenser_to_target`, `ghost_hand_sprinkle`, `timer_ring`) to prefabs.

**ArrowCueController.cs**
- Animated bouncing arrow positioned above a target transform.

**HighlightCueController.cs**
- Soft / pulse alpha+scale highlight that follows a target transform. Two modes: `soft_highlight`, `pulse_highlight`.

**GuidanceHudController.cs**
- In-HMD World Space HUD: step instruction text, spice name, gram progress bar, timer countdown.
- All UI fields optional (null-safe); supports legacy `UnityEngine.UI.Text` or TMP swap.

**HudFollowCamera.cs**
- Lazy lerp follow so the HUD drifts with head pose (`m_posLerpSpeed`, `m_rotLerpSpeed`, `m_billboardYOnly`) instead of rigidly attaching to the camera.

**SceneObjectRegistry.cs**
- Resolves a label string → `Transform`. Priority: spawned spatial marker > live YOLO detection box > null.

**VisionRvHudController.cs**
- Togglable in-headset R&V debug overlay: live inference FPS, per-detection list, planner/backend state, latency stats (p50/p95/max).

**MarkerReviewRaySelector.cs**
- Ray-selector for ingredient-review phase using `Physics.Raycast` against marker colliders (NOT `EnvironmentRaycastManager` — that hits real-world geometry, not Unity GameObjects).

---

### New Test Tools — `Software/src/web_app/tools/`

**connection_soak_test.py**
- 30-minute soak test polling `GET /state` (or `GET /rv_state`) every second.
- Logs to `results/connection_soak.csv`; reports max reconnect gap.
- Acceptance criterion: no connectivity gap > 5 s.

**latency_burst_test.py**
- Bursts `POST /rv_event` at 10 Hz for 60 s; measures end-to-end latency.
- Logs to `results/latency_burst.csv`; reports PASS/FAIL.
- Acceptance criterion: p95 ≤ 150 ms AND dropped = 0.

---

### `backend_llm_ready.py` (721 lines)
- Clean snapshot of the backend with LLM integration + core state machine but without R&V telemetry endpoints. Kept as reference/backup alongside the full `backend.py`.

---

### Architectural Shifts Summary

| Area | Mar. 28 baseline | Apr. 26 |
|---|---|---|
| Recipe generation | `_generate_mock_recipe()` placeholder | Real OpenAI LLM call with strict JSON schema + Pydantic validation, mock as fallback |
| ESP32 comms | WiFi HTTP polling loop | BLE GATT peripheral + separate `ble_bridge.py` relay |
| Step payload | `instruction`, `type`, `dispense` | + `step_id`, `render_plan`, `completion_mode`, `targets`, `destination`, `schema_version` |
| AR guidance | Not implemented | Full `RecipeGuidanceManager` + `CueRenderer` + 4 cue controllers |
| HUD | Not implemented | `GuidanceHudController` + `HudFollowCamera` lazy follow |
| R&V verification | Not implemented | `/vision_frame`, `/rv_event`, `/rv_state` + `VisionRvHudController` + 2 CLI test tools |
| Label resolution | N/A | `SceneObjectRegistry` (marker-priority lookup) |

---

# Mar. 28th
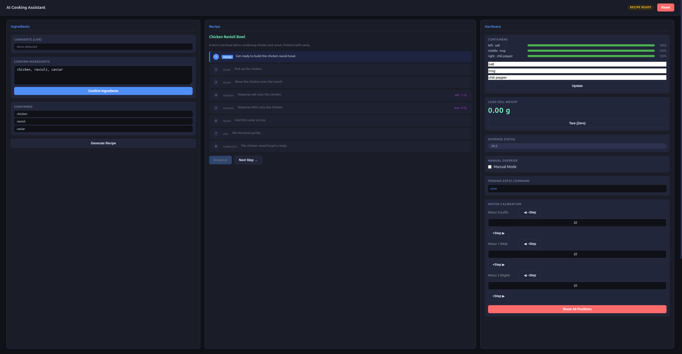
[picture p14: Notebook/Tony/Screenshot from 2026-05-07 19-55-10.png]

### API Contract — `Software/doc/api_state_contract.md`
- Created new contract doc freezing all state names, canonical spice strings, and JSON payload shapes for Quest ↔ Backend ↔ ESP32
- Full endpoint reference table

### Backend — `Software/src/web_app/backend.py`
- Built full FastAPI \[7\] state-machine orchestrator from scratch
- `system_state` dict as single source of truth (`demo_state`, ingredients, recipe, steps, dispense status, weight, containers)
- All endpoints implemented: `/state`, `/reset`, `/candidate_ingredients`, `/ingredients_confirmed`, `/generate_recipe`, `/current_step`, `/advance_step`, `/dispense_step`, `/pending_command`, `/command_result`, `/status_update`, `/set_containers`, `/manual_override`, `/manual_dispense`
- Mock recipe generator placeholder (`_generate_mock_recipe`) — swap for LLM call later

### Web Dashboard — `Software/src/web_app/main/`
- `index.html` — three-column layout: ingredients, recipe steps, hardware
- `script.js` — polls `/state` every 2s; all button actions wired; renders live state badge, step list, container level bars, load cell weight, pending ESP32 command
- `style.css` — dark theme, state-colored badges, step progress visualization

### ESP32 Firmware \[8\] — `Software/src/esp_driver/src/main.cpp`
- Full rewrite from passive `WebServer` → active `HTTPClient` polling loop
- Polls `GET /pending_command` every 1s; runs closed-loop dispense; POSTs to `/command_result`
- HX711 \[9\] load cell tared on boot; ±0.2g tolerance, 15s timeout
- 3 motors in `AccelStepper::DRIVER` (step/dir) mode, indexed by `container_index`
- `TEST_MOTOR_INDEX` constant: set `0/1/2` for single-motor testing, `-1` for production
- `platformio.ini`: added `HX711` + `ArduinoJson`, removed TB6612

### Unity — New Files (`DetectionManager/Scripts/`)
- `DetectionResult.cs` — structured detection model (`ClassId`, `ClassName`, `Score`, `BoundingBox`); replaces raw tuple
- `IngredientInventoryManager.cs` — candidate stability tracking (SeenCount + timeout), confirmed list, periodic POST on set change
- `BackendClient.cs` — all HTTP traffic via `UnityWebRequest` coroutines; configurable `m_baseUrl`

### Unity — Modified Files
- `SentisInferenceRunManager.cs` (Unity Sentis \[6\]) — `m_detections` → `List<DetectionResult>`; NMS preserves score + class name; calls `m_ingredientInventory.UpdateCandidates()` each inference frame
- `SentisInferenceUiManager.cs` — added `DrawUIBoxes(List<DetectionResult>...)` overload; existing rendering untouched
- `DetectionManager.cs` — added `m_ingredientInventory` + `m_backendClient` references; A button confirms ingredients + triggers recipe generation; B button also clears inventory

### Next Steps
> Inside the esp_driver folder, change backend IP address to ***new IP address every time***

> Inside the Unity files
    - Add IngredientInventoryManager and BackendClient as components on a GameObject in your scene
    - Wire the m_ingredientInventory and m_backendClient serialized fields in SentisInferenceRunManager and DetectionManager in the Inspector
    - Set m_baseUrl in BackendClient to your backend machine's LAN IP

# Feb. 15th
**Source basis:** Uploaded project proposal, Lab-Notebook guideline, `NuChef_Vision_Model_Bakeoff.ipynb`, `ingredients.png`, `ingredients_debug_pred.jpg`, and related NuChef project files available in this ChatGPT workspace.

> Note: Exact dates of the original conversations were not available, so the entries below are reconstructed dated entries for notebook use.

---

## Entry 1 - Vision subsystem objective and model-bakeoff plan

**Date:** 2026-02-07

### Objective

Define a practical comparison workflow for the project vision subsystem. The project goal is to recognize available ingredients from headset camera imagery, produce a structured ingredient list, and feed that list into recipe generation and AR guidance. The proposal allowed YOLOv8/YOLO11 \[1\]\[2\] or FastSAM \[3\] for candidate regions, followed by CLIP-style classification \[4\] if needed.

### Record of work

- Decided that YOLO should be the first working baseline because it gives both localization and class labels in one pass.
- Framed the notebook as a vision model bakeoff rather than a single training script.
- Selected the comparison candidates:
  1. YOLOv11 pretrained baseline \[1\]\[2\].
  2. YOLOv11 fine-tuned on the ingredient dataset \[5\].
  3. CNN crop classifier baseline trained on ground-truth crops.
  4. Tracking plus temporal smoothing to reduce repeated detector computation.
- Defined the goal of the notebook output as a concise performance table comparing accuracy, precision, recall, F1, and inference time.

### Decisions and rationale

- YOLO-first was chosen because it is the fastest route to an end-to-end Quest/AR demo with boxes and labels.
- CNN crop classification was kept as a diagnostic baseline: if crops classify well but YOLO end-to-end performs poorly, localization or dataset/domain shift is the bottleneck.
- Tracking was included because real-time headset guidance may not need detector inference on every frame.

### Figures / attachments

- **Fig. 1:** `ingredients.png` - example crowded ingredient test image used to stress-test detection.
- **Fig. 2:** `ingredients_debug_pred.jpg` - debug prediction image showing excessive low-confidence boxes and class confusion.

---

## Entry 2 - Notebook setup and dataset interface

**Date:** 2026-02-01

### Objective

Create a reusable Jupyter notebook scaffold that can run locally or in Colab and point to a YOLO-format ingredient dataset.

### Record of work

- Built notebook setup cells for optional Colab Drive mounting and optional pip installs.
- Imported `os`, `time`, `math`, `random`, `shutil`, `dataclasses`, `pathlib`, `typing`, `numpy`, `pandas`, `yaml`, `cv2`, and `torch`.
- Set a fixed random seed, `SEED = 445`, for reproducibility.
- Added a CUDA/PyTorch diagnostic cell to report whether GPU acceleration is available.
- Added configuration variables (dataset: Roboflow AI Recipes Recommendation \[5\]):
  - `DATA_YAML = os.getenv("NUCHEF_DATA_YAML", "data/data.yaml")`
  - `YOLO_BASE_WEIGHTS = os.getenv("NUCHEF_YOLO_BASE", "yolo11n.pt")`
  - `YOLO_FT_WEIGHTS = os.getenv("NUCHEF_YOLO_FT", "PATH/TO/best.pt")`
  - `EVAL_SPLIT = "test"`
  - `CONF_THRESH = 0.25`
  - `IOU_THRESH = 0.50`
  - `WARMUP_ITERS = 5`

### Decisions and rationale

- Environment variables were used so the same notebook could run on different machines without editing code.
- The default model was `yolo11n.pt` because the nano model is more realistic for edge/headset-style inference and later Unity Sentis deployment.
- The test split was selected as the default for final comparison; validation split can still be used during development.

---

## Entry 3 - Dataset parsing and class-frequency analysis

**Date:** 2026-02-03

### Objective

Read the YOLO `data.yaml` file, locate the split image/label directories, parse labels, and understand class frequency.

### Record of work

- Implemented helpers to load `data.yaml` and normalize the YOLO class names list/dictionary.
- Implemented split directory resolution using the dataset path declared inside `data.yaml`.
- Inferred the matching labels directory by replacing `images` with `labels`.
- Implemented generic YOLO label parsing that works for detection labels and segmentation-style labels by reading class id plus remaining floats.
- Counted ground-truth object frequency per class over the selected image split.
- Displayed the top 20 most common classes.
- Generated `SUGGESTED_CORE` from the top-K most frequent classes, with `TOPK` initially set to 50.

### Decisions and rationale

- The bakeoff should not blindly train/evaluate on extremely sparse classes.
- A top-K core class list gives a practical way to target 30-50 reliable ingredient/object classes for a demo.
- Sparse or non-core classes can either be dropped or mapped to `unknown`, depending on whether the goal is clean classification or robust demo behavior.

---

## Entry 4 - Filtered dataset generation

**Date:** 2026-02-06

### Objective

Create a smaller filtered dataset focused on core ingredients/classes and optionally map all non-core detections to an `unknown` class.

### Record of work

- Implemented `make_filtered_dataset()` to copy/hardlink image files into a new dataset folder.
- Remapped labels from original class ids into a new core-class index set.
- Added `ADD_UNKNOWN = True` to map non-core labels into an `unknown` class.
- Added `DROP_NONCORE = False` as an alternate behavior for dropping non-core labels.
- Wrote a new filtered `data.yaml` containing the remapped class names.

### Decisions and rationale

- Keeping an `unknown` class is useful for real kitchen scenes where the image contains many objects that are not part of the supported recipe pipeline.
- Filtering classes makes the training objective match the demo objective: stable recognition of a manageable set of ingredients rather than broad open-world object recognition.

---

## Entry 5 - YOLOv11 fine-tuning section

**Date:** 2026-02-15

### Objective

Fine-tune a YOLOv11 detector on the ingredient dataset and save the best checkpoint for comparison against the pretrained baseline.

### Record of work

- Imported `YOLO` from `ultralytics` \[2\].
- Defined `RUNS_DIR` so training artifacts are saved inside the current project folder.
- Implemented `train_yolo_ultralytics(weights, data_yaml, task, epochs, imgsz, batch, device, project, name)`.
- Configured training with:
  - `weights = YOLO_BASE_WEIGHTS`
  - `data = DATA_YAML`
  - `task = "detect"`
  - `epochs = 50`
  - `imgsz = 640`
  - `batch = -1` for automatic batch selection
  - `device = 0`
  - run name = `yolo11n_ingredients_det_ft`
- Stored the resulting checkpoint path in `YOLO_FT_WEIGHTS`.

### Equations

**Eq. 7 — YOLO fine-tuning multitask loss.** The detector training objective is a weighted sum of three losses:

$$
\mathcal{L}
= \lambda_{\mathrm{box}}\mathcal{L}_{\mathrm{box}}
+ \lambda_{\mathrm{obj}}\mathcal{L}_{\mathrm{obj}}
+ \lambda_{\mathrm{cls}}\mathcal{L}_{\mathrm{cls}}
$$

where $\mathcal{L}_{\mathrm{box}}$ is box regression loss, $\mathcal{L}_{\mathrm{obj}}$ is objectness loss, and $\mathcal{L}_{\mathrm{cls}}$ is classification loss. Default Ultralytics weights were used; no manual tuning was needed for the ingredient domain.

### Decisions and rationale

- Detection was chosen first, not segmentation, because bounding boxes are simpler to evaluate, visualize, and integrate with AR target highlighting.
- The notebook keeps `task="detect"` configurable so segmentation can be tested later if object masks become useful.

---

## Entry 6 - Detection metric implementation

**Date:** 2026-04-07

### Objective

Evaluate YOLO detections with interpretable instance-level metrics and inference speed.

### Record of work

- Defined a `Det` dataclass with `bbox`, `cls`, and `conf` fields.
- Implemented IoU for `xyxy` bounding boxes.
- Implemented greedy matching between predictions and ground truth.
- Counted true positives, false positives, and false negatives using `IoU >= 0.50` and class match.
- Defined detection-style accuracy as:

```text
Accuracy = TP / (TP + FP + FN)
```

- Computed precision, recall, F1, and average inference time in milliseconds.
- Added warmup iterations before timing to avoid first-run overhead.

### Equations

**Eq. 1 — Detection output set.** For each RGB frame the inference subsystem returns:

$$
\mathcal{D} = \left\{\left(c_i, p_i, \mathbf{b}_i\right)\right\}_{i=1}^{N}, \qquad
c_i \in \mathcal{C}, \quad
p_i \in [0,1], \quad
\mathbf{b}_i = \left(x_i, y_i, w_i, h_i\right)
$$

**Eq. 2 — Intersection over Union.** For two axis-aligned boxes $A$ and $B$:

$$
\mathrm{IoU}(A,B)
= \frac{\left|A \cap B\right|}{\left|A\right| + \left|B\right| - \left|A \cap B\right|}
\in [0,1]
$$

A prediction is matched to ground truth only if $\mathrm{IoU} \geq 0.50$ **and** labels agree (greedy, confidence-sorted).

**Eq. 3 — Precision, recall, F1.**

$$
P = \frac{\mathrm{TP}}{\mathrm{TP}+\mathrm{FP}}, \qquad
R = \frac{\mathrm{TP}}{\mathrm{TP}+\mathrm{FN}}, \qquad
F_1 = \frac{2PR}{P+R}
$$

**Eq. 4 — Detection accuracy proxy.** Penalises both missed objects and false alarms:

$$
\mathrm{Acc} = \frac{\mathrm{TP}}{\mathrm{TP}+\mathrm{FP}+\mathrm{FN}}
$$

### Decisions and rationale

- Instance-level TP/FP/FN is easier to interpret for the project than only relying on Ultralytics aggregate logs.
- Timing was measured in the same loop as prediction so speed tradeoffs can be compared directly with accuracy.
- IoU threshold set to 0.50 (standard COCO definition); confidence threshold 0.25 matches deployment setting.

---

## Entry 7 - CNN crop classifier baseline

**Date:**  2026-04-11

### Objective

Create a classification-only baseline to separate whether the visual class is recognizable from whether the detector can localize it correctly.

### Record of work

- Created crops from YOLO ground-truth boxes into `crops_dataset/{split}/{class_name}/`.
- Resized crops to `CROP_SIZE = 224`.
- Built torchvision dataloaders with image augmentations for training and deterministic resizing for evaluation.
- Implemented `build_classifier()` for common architectures such as ResNet18.
- Evaluated classification accuracy, macro precision, macro recall, macro F1, and milliseconds per crop.

### Equations

**Eq. 8 — ResNet-18 crop-classifier head.** The pretrained backbone's final layer is replaced with a task-specific linear head:

$$
f_{\theta}(\mathbf{x}) = W_{\mathrm{new}}\,\phi(\mathbf{x}) + \mathbf{b}
$$

where $\phi(\mathbf{x}) \in \mathbb{R}^{512}$ is the ResNet-18 embedding, $W_{\mathrm{new}} \in \mathbb{R}^{C \times 512}$, and $C$ is the number of ingredient classes. Only $W_{\mathrm{new}}$ and $\mathbf{b}$ are trained (frozen backbone, transfer learning).

### Decisions and rationale

- A crop classifier is not the final deployment path by itself, but it is a useful bottleneck test.
- If crop classification is strong but YOLO detection is weak, the bottleneck is localization or domain shift — not class appearance.
- Frozen backbone keeps training time short and avoids overfitting on the small ingredient crop set.

---

## Entry 8 - Tracking and temporal smoothing

**Date:** 2026-04-15

### Objective

Estimate whether the system can improve runtime by detecting every N frames and tracking detections in between.

### Record of work

- Implemented a lightweight IoU tracker with `Track` dataclass fields: `track_id`, `bbox`, class history, confidence history, age, and missed count.
- Added exponential moving average smoothing for bounding boxes.
- Added confidence-weighted class voting over recent frames.
- Implemented `run_video_benchmark(video_path, weights, detect_every, conf, iou, max_frames, out_video)`.
- Separated detector time and tracker time to estimate effective frame processing time.

### Equations

**Eq. 5 — Exponential moving average for bounding boxes.** Each matched track $k$ is smoothed across frames:

$$
\mathbf{b}_k^{(t)}
= \alpha\,\mathbf{b}_k^{(t-1)}
+ (1-\alpha)\,\hat{\mathbf{b}}_k^{(t)}, \qquad \alpha \in (0,1)
$$

Used $\alpha = 0.7$: favours the previous box and suppresses per-frame jitter without introducing excessive lag.

**Eq. 6 — Confidence-weighted class vote.** Instead of trusting a single frame, the tracker votes over the last $K$ detections:

$$
S(c) = \sum_{i \in \mathcal{H}_K} w_i\,\mathbf{1}[\hat{c}_i = c], \qquad
\hat{c}_k^{(t)} = \operatorname*{arg\,max}_{c}\,S(c)
$$

where $w_i = p_i$ (detector confidence for observation $i$) and $\mathcal{H}_K$ is the $K$-frame history window.

### Decisions and rationale

- Tracking was included because AR guidance prefers stable visual targets, not flickering labels.
- Detecting every N frames can reduce compute load while smoothing can reduce label jitter.
- Class voting over a history window is more robust than any single-frame label — especially important when the Quest camera moves.

---

## Entry 9 - Performance table and interpretation checklist

**Date:** 2026-04-15

### Objective

Produce the final summary table requested by the bakeoff workflow.
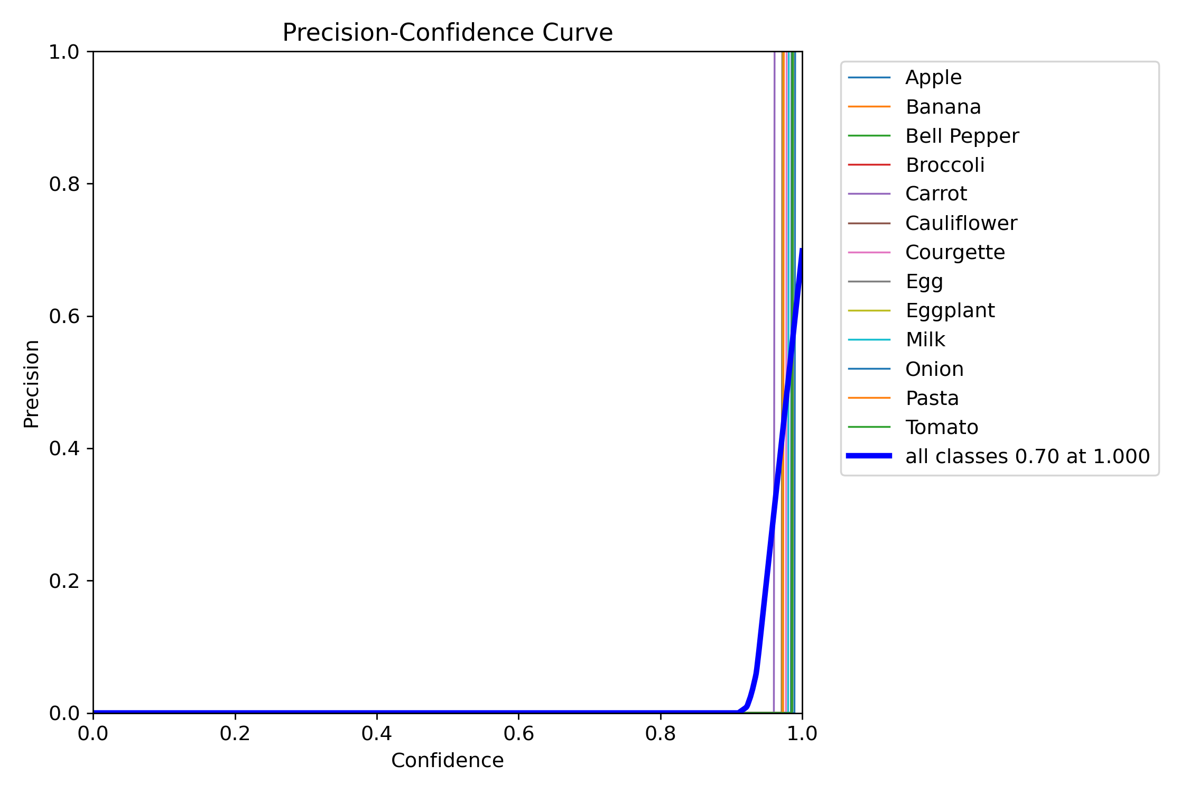
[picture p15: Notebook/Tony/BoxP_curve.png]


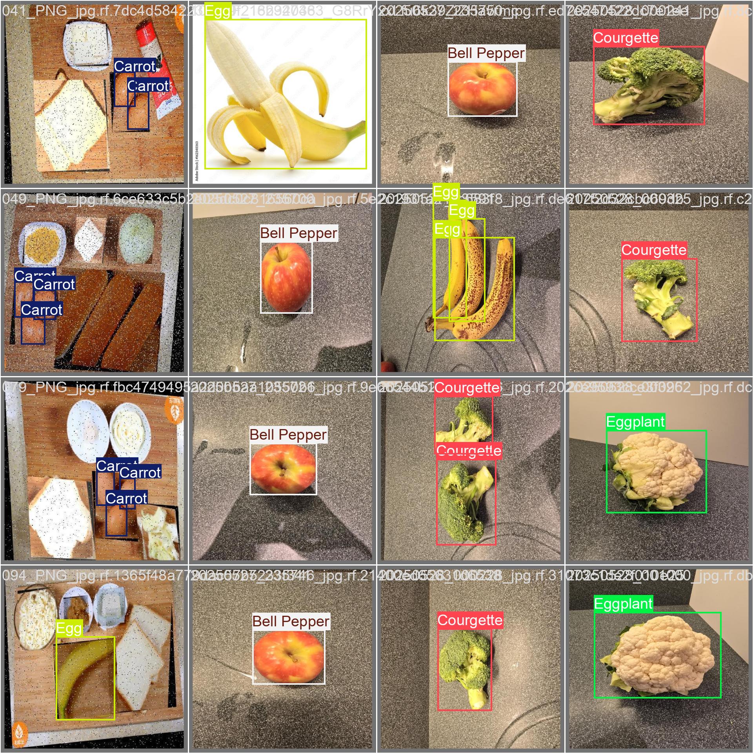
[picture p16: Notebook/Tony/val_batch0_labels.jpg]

### Record of work
- Defined `performance_table.csv` columns:
  - Model Name
  - Dataset
  - Accuracy (%)
  - Precision (%)
  - Recall (%)
  - F1 Score
  - Inference Time (ms)
  - Notes
- Implemented `load_or_init_table()`, `add_result()`, and `save_table()`.
- Added rows for YOLOv11 fine-tuned and CNN ResNet18 crop classifier once their metric dictionaries are available.
- Added a notebook interpretation checklist:
  - If CNN-on-crops is good but YOLO end-to-end is bad, localization/data/domain shift is the bottleneck.
  - If YOLO fine-tuning improves over baseline, keep iterating data and labels.
  - If speed is insufficient, increase `detect_every` and use tracking/smoothing.

### Decisions and rationale

- The CSV table makes model choices easy to justify in design review and final report.
- The interpretation checklist turns the notebook from a training script into an engineering decision tool.

---

## Entry 10 - Integration implications for Quest / Unity Sentis pipeline

**Date:** Reconstructed 2026-04-15

### Objective

Connect the bakeoff results to the eventual AR cooking guidance system.

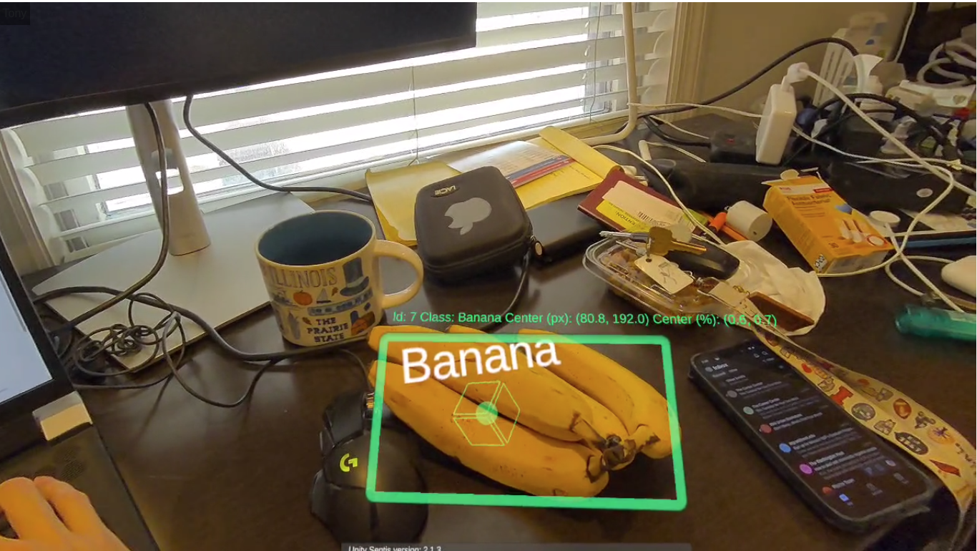
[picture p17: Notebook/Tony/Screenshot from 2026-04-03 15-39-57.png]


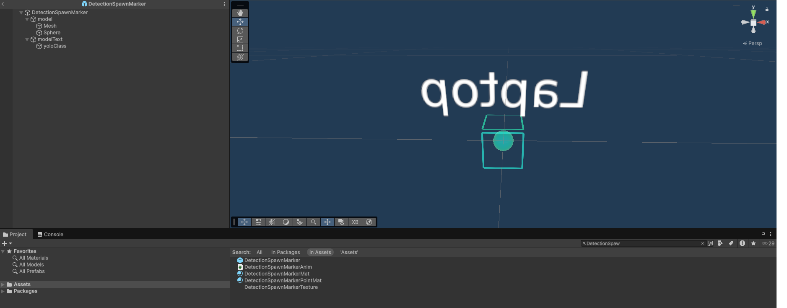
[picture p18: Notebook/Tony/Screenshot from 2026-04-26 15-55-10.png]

### Record of work

- Kept the model choice aligned with the final Quest/Unity Sentis \[6\] workflow.
- The later Unity code uses YOLO detections with class ids, class names, scores, and bounding boxes \[1\].
- The project direction moved toward stable candidate ingredient tracking, user confirmation, backend recipe generation, and AR step guidance.

### Decisions and rationale

- The notebook output should select a model/checkpoint for deployment, but the application must still add stability logic and user confirmation.
- A noisy detector output should not directly become a recipe. Confirmed ingredients should be posted to the backend after repeated detections and/or user confirmation.

---

# Jan. 25th

## Project Kickoff — System Architecture & Design Decisions

**Date:** 2026-01-25

### Objective

Define the high-level system architecture for NuChef before implementation begins. Record the key design decisions, subsystem boundaries, communication flow, and the initial state machine so that later implementation work has a clear specification to follow.

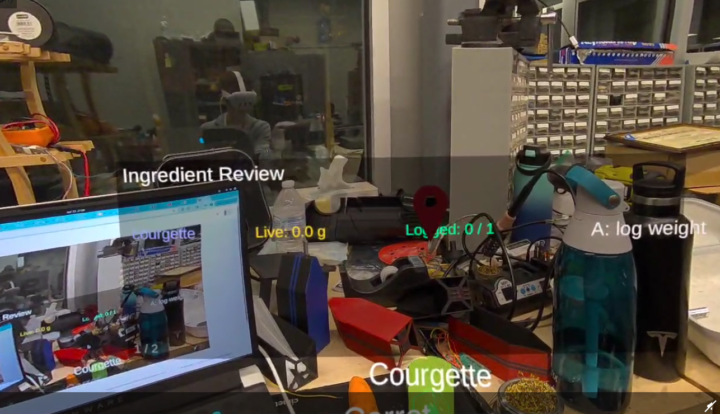
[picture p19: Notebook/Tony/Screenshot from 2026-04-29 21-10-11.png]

### Record of work

#### A. Subsystem breakdown

The NuChef system is divided into four interacting subsystems:

- **Meta Quest 3 / Unity AR UI** \[12\]\[13\] — captures RGB frames from the passthrough camera \[14\], runs local YOLO inference \[1\], lets the user confirm detected ingredients, and renders step-by-step AR guidance overlays.
- **FastAPI backend** \[7\] — central state machine and recipe planner. Owns the cooking session lifecycle, validates events from Quest and ESP32 \[8\], calls the LLM recipe planner \[10\], and exposes a web dashboard for manual control.
- **BLE bridge** — a lightweight Python relay (`bleak` + `httpx`) running on the host laptop. Polls the backend for pending dispense commands and forwards them to the ESP32 over BLE; relays ESP32 weight/result notifications back to the backend.
- **ESP32 dispenser module** \[8\] — BLE GATT peripheral with HX711 load cell \[9\] and three stepper motors \[11\]. Receives dispense commands, runs closed-loop weight control, and notifies the bridge when done.

#### B. Design decisions

1. **Unity over raw Android Camera API** — Unity provides a faster route to AR annotations, spatial anchors, HUD panels, and controller/hand interaction. The Meta XR SDK integrates directly with Unity.
2. **Local inference on Quest (not streamed to backend)** — streaming video to the backend would introduce ~100–200 ms round-trip latency for every frame and require a high-bandwidth local network. Running inference on-device with a compact YOLOv11 model keeps the AR overlay responsive. Accepted tradeoff: ~6% accuracy reduction vs. the full-size model.
3. **Single-pass YOLO vs. detect-then-classify pipeline** — a two-stage crop-classify pipeline adds latency and can compound localization + classification errors. A fine-tuned single-stage detector is simpler and fast enough for the demo scenario.
4. **Explicit backend state machine** — cooking steps must be ordered and serialized. An explicit state machine eliminates ambiguous concurrent transitions (e.g., scanning while dispensing) and makes error recovery deterministic.

#### C. Communication flow (Fig. 1)

**Fig. 1 — System communication dataflow.**

```mermaid
flowchart LR
    Q["Meta Quest 3 / Unity AR UI\nLocal YOLO inference + user input"] -->|"candidate ingredients, confirmations, step events"| B["FastAPI backend\nstate machine + recipe planner"]
    B -->|"current_step JSON + render_plan"| Q
    B -->|"pending dispense / tare command"| G["BLE bridge\nPython bleak + httpx"]
    G -->|"BLE CMD_CHAR write"| E["ESP32 dispenser\nstepper motors + HX711 load cell"]
    E -->|"BLE RSLT_CHAR + WT_CHAR notify"| G
    G -->|"/command_result + /status_update"| B
    B -->|"live state"| D["Web dashboard\ncontainer setup + manual override"]
```

#### D. Initial state machine design (Fig. 2)

**Fig. 2 — Backend state machine.**

```mermaid
stateDiagram-v2
    [*] --> IDLE
    IDLE --> SCANNING: start camera / live detections
    SCANNING --> INGREDIENTS_CONFIRMED: user confirms detections
    INGREDIENTS_CONFIRMED --> RECIPE_READY: planner generates steps
    RECIPE_READY --> DISPENSING_STEP: current step requires seasoning
    RECIPE_READY --> USER_COOK_STEP: current step is user action
    DISPENSING_STEP --> USER_COOK_STEP: dispense done
    USER_COOK_STEP --> DISPENSING_STEP: next step requires seasoning
    USER_COOK_STEP --> COMPLETE: final user step done
    COMPLETE --> IDLE: reset
    IDLE --> ERROR: invalid event / hardware fault
    SCANNING --> ERROR: invalid event / hardware fault
    INGREDIENTS_CONFIRMED --> ERROR: invalid event / hardware fault
    RECIPE_READY --> ERROR: invalid event / hardware fault
    DISPENSING_STEP --> ERROR: invalid event / hardware fault
    USER_COOK_STEP --> ERROR: invalid event / hardware fault
    ERROR --> IDLE: reset
```

State definitions:

| State | Description |
|---|---|
| `IDLE` | Waiting for user to begin session |
| `SCANNING` | Quest running YOLO inference, accumulating candidate ingredients |
| `INGREDIENTS_CONFIRMED` | User has accepted the ingredient list; waiting for recipe |
| `RECIPE_READY` | LLM/planner has returned ordered recipe steps |
| `DISPENSING_STEP` | ESP32 dispensing seasoning; waiting for weight confirmation |
| `USER_COOK_STEP` | User executing a manual cooking instruction |
| `COMPLETE` | All steps done |
| `ERROR` | Hardware/validation fault; requires reset |

### Verification plan

- Full end-to-end path: `IDLE → SCANNING → INGREDIENTS_CONFIRMED → RECIPE_READY → DISPENSING_STEP → USER_COOK_STEP → COMPLETE`.
- Dispense verification: backend creates exactly one `pending_command`, BLE bridge writes it once, ESP32 returns `command_result`, backend clears `pending_command`. Record target grams, actual grams, scale baseline, final weight, motor slot, and any timeout/error.
- Failure modes: network disconnect, stale pending command, command ID mismatch, BLE reconnect delay, load-cell tare drift, HUD/cue cleanup on `complete`.

### Decisions and rationale

- Communication layer should stay **intentionally minimal** — backend does state validation and orchestration, not heavy CV computation.
- Detection output must be structured (`class`, `confidence`, `bounding box`) so the recipe planner and AR cue system can consume it directly without ambiguity.

---

# References

\[1\] J. Redmon, S. Divvala, R. Girshick, and A. Farhadi, "You Only Look Once: Unified, Real-Time Object Detection," *arXiv preprint arXiv:1506.02640*, 2015. [Online]. Available: https://arxiv.org/abs/1506.02640

\[2\] Ultralytics, "YOLOv8 Documentation," [Online]. Available: https://docs.ultralytics.com/. [Accessed: Feb. 13, 2026].

\[3\] A. Kirillov et al., "Segment Anything," in *Proc. IEEE/CVF Int. Conf. Computer Vision*, 2023, pp. 4015–4026. [Online]. Available: https://arxiv.org/abs/2304.02643

\[4\] A. Radford et al., "Learning Transferable Visual Models From Natural Language Supervision," in *Proc. 38th Int. Conf. Machine Learning*, 2021, pp. 8748–8763. [Online]. Available: https://proceedings.mlr.press/v139/radford21a.html

\[5\] AI Recipes Recommendations, "AI Recipes Recommendation Dataset," Roboflow Universe. [Online]. Available: https://universe.roboflow.com/ai-recipes-recommendations/ai-recipes-recommendation. [Accessed: Feb. 13, 2026].

\[6\] Unity Technologies, "Unity Sentis: AI Inference Engine," [Online]. Available: https://docs.unity3d.com/Packages/com.unity.sentis. [Accessed: Feb. 13, 2026].

\[7\] FastAPI, "FastAPI Documentation," [Online]. Available: https://fastapi.tiangolo.com/. [Accessed: Feb. 13, 2026].

\[8\] Espressif Systems, *ESP32 Technical Reference Manual*. [Online]. Available: https://www.espressif.com/. [Accessed: Feb. 13, 2026].

\[9\] Avia Semiconductor, *HX711: 24-Bit ADC for Weigh Scales Datasheet*. [Online]. Available: https://cdn.sparkfun.com/datasheets/Sensors/ForceFlex/hx711_english.pdf. [Accessed: Feb. 13, 2026].

\[10\] OpenAI, "GPT Models API Documentation," [Online]. Available: https://platform.openai.com/docs. [Accessed: Feb. 13, 2026].

\[11\] StepperOnline, *17HE15-1504S Full Datasheet*. [Online]. Available: https://www.artme-3d.de/wp-content/uploads/2024/03/17HE15-1504S.pdf. [Accessed: Mar. 11, 2026].

\[12\] Meta Platforms, Inc., "Meta Quest Developer Documentation," Meta Horizon OS Developers. [Online]. Available: https://developers.meta.com/horizon/. [Accessed: Feb. 13, 2026].

\[13\] Meta Platforms, Inc., "Unity Passthrough Camera API Samples," GitHub. [Online]. Available: https://github.com/oculus-samples/Unity-PassthroughCameraApiSamples. [Accessed: Feb. 13, 2026].

\[14\] Meta Platforms, Inc., "Passthrough Window Tutorial," Meta Horizon OS Developers. [Online]. Available: https://developers.meta.com/horizon/documentation/unity/unity-passthrough-tutorial-passthrough-window/. [Accessed: Feb. 13, 2026].

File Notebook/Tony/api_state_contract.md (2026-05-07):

# API & State Contract
## AI Nutritious Culinary Assistant

> **Created:** March 28, 2026

---

## 1. Canonical State Names

| State | Description |
|---|---|
| `idle` | System waiting, nothing active |
| `scanning` | Quest is detecting ingredients |
| `ingredients_confirmed` | User confirmed ingredient list |
| `recipe_ready` | Backend generated recipe, steps loaded |
| `dispensing_step` | ESP32 is dispensing for current step |
| `user_cook_step` | User performing a non-dispense cooking step |
| `complete` | All steps finished |
| `error` | Recoverable error state |
| `manual_override` | Direct hardware control active |

---

## 2. Canonical Spice Strings

Always use exactly these strings (lowercase, no variation):

```
"salt"
"black pepper"
"garlic powder"
```

Container index mapping (fixed):

```
containers[0] = "salt"
containers[1] = "black pepper"
containers[2] = "garlic powder"
```

---

## 3. System State Shape

```json
{
  "demo_state": "idle",
  "candidate_ingredients": [],
  "confirmed_ingredients": [],
  "recipe": null,
  "current_step_index": -1,
  "containers": ["salt", "black pepper", "garlic powder"],
  "container_levels": [100, 100, 100],
  "weight": 0.0,
  "dispense_status": "idle",
  "manual_override": false,
  "last_error": null
}
```

---

## 4. Recipe Shape

```json
{
  "name": "Garlic Herb Chicken",
  "description": "Simple pan-seared chicken with garlic and herbs.",
  "steps": [
    {
      "index": 0,
      "instruction": "Season chicken with salt.",
      "type": "dispense",
      "dispense": {
        "spice": "salt",
        "grams": 3.0
      }
    },
    {
      "index": 1,
      "instruction": "Add black pepper to taste.",
      "type": "dispense",
      "dispense": {
        "spice": "black pepper",
        "grams": 1.5
      }
    },
    {
      "index": 2,
      "instruction": "Sear chicken on medium heat for 6 minutes per side.",
      "type": "cook",
      "dispense": null
    },
    {
      "index": 3,
      "instruction": "Finish with garlic powder and rest for 5 minutes.",
      "type": "dispense",
      "dispense": {
        "spice": "garlic powder",
        "grams": 2.0
      }
    }
  ]
}
```

Step `type` is either `"dispense"` or `"cook"`.

---

## 5. JSON Payloads

### Quest → Backend

**POST /ingredients_confirmed**
```json
{
  "ingredients": ["chicken", "garlic", "olive oil"]
}
```

**POST /candidate_ingredients**  *(Quest pushes live detections)*
```json
{
  "ingredients": ["chicken", "garlic"]
}
```

---

### Backend → Quest (response from GET /current_step)

```json
{
  "step_index": 1,
  "instruction": "Add black pepper to taste.",
  "type": "dispense",
  "dispense": {
    "spice": "black pepper",
    "grams": 1.5
  },
  "total_steps": 4
}
```

---

### Backend → ESP32 (response from GET /pending_command)

```json
{
  "command_id": "cmd_20260325_001",
  "action": "dispense",
  "spice": "black pepper",
  "container_index": 1,
  "target_grams": 1.5
}
```

If no command is pending:
```json
{
  "command_id": null,
  "action": "none"
}
```

---

### ESP32 → Backend

**POST /command_result**
```json
{
  "command_id": "cmd_20260325_001",
  "status": "done",
  "actual_grams": 1.48,
  "weight": 312.4
}
```

**POST /status_update**  *(periodic heartbeat)*
```json
{
  "weight": 312.4,
  "container_levels": [97, 98, 100]
}
```

---

## 6. All Endpoints

| Method | Path | Caller | Description |
|---|---|---|---|
| GET | `/state` | Any | Full system state |
| POST | `/candidate_ingredients` | Quest | Push live detections |
| POST | `/ingredients_confirmed` | Quest / Dashboard | Lock ingredient list |
| POST | `/generate_recipe` | Dashboard | Trigger recipe generation |
| GET | `/current_step` | Quest / Dashboard | Get active step |
| POST | `/advance_step` | Quest / Dashboard | Move to next step |
| POST | `/dispense_step` | Dashboard | Manually trigger dispense |
| GET | `/pending_command` | ESP32 | Poll for dispense command |
| POST | `/command_result` | ESP32 | Report dispense outcome |
| POST | `/status_update` | ESP32 | Heartbeat weight/levels |
| POST | `/set_containers` | Dashboard | Rename containers |
| POST | `/manual_override` | Dashboard | Toggle manual mode |
| POST | `/reset` | Dashboard | Reset to idle |

---

## 7. Rules

1. `demo_state` is the single source of truth — never duplicate state in Unity or ESP32.
2. Quest only POSTs; it never mutates backend state directly beyond ingredient confirmation.
3. ESP32 never generates commands — it only executes and reports.
4. Spice names must always match the canonical list exactly (case-sensitive).
5. `command_id` must be echoed back in `/command_result` for correlation.

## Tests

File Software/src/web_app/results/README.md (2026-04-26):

# NuChef — R&V Results

This folder holds output from the R&V measurement tools.

Generated files:
- `latency_burst.csv` / `latency_burst_summary.txt` — from `tools/latency_burst_test.py`
- `connection_soak.csv` / `connection_soak_summary.txt` — from `tools/connection_soak_test.py`
- `vision_val_summary.txt` — manual YOLO validation metrics entry
- `confusion_matrix.png` — YOLO validation confusion matrix
- `sample_predictions/` — annotated prediction images

Generate with:
    python tools/latency_burst_test.py --url http://<backend>:8000
    python tools/connection_soak_test.py --url http://<backend>:8000 --duration-min 30

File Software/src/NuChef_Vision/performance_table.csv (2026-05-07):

Model Name | Dataset | Accuracy (%) | Precision (%) | Recall (%) | F1 Score | Inference Time (ms) | Notes
YOLOv11n-FT (best_2) | Original 13-class | 85.1 | 91.5 | 92.0 | 0.9175 | 6.15 | mAP@0.5:0.95=0.851; max_det=20; conf=0.25, iou=0.5
CNN (ResNet18) | GT Crops | 91.84 | 93.01 | 92.3 | 0.924 | 0.408 | cls-only on GT crops; 15 epochs; top-1=91.8%; macro metrics

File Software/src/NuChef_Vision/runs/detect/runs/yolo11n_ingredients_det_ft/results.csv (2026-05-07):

epoch | time | train/box_loss | train/cls_loss | train/dfl_loss | metrics/precision(B) | metrics/recall(B) | metrics/mAP50(B) | metrics/mAP50-95(B) | val/box_loss | val/cls_loss | val/dfl_loss | lr/pg0 | lr/pg1 | lr/pg2
1 | 16.3747 | 0.72114 | 3.78857 | 1.12902 | 0.06218 | 0.49036 | 0.15919 | 0.14457 | 0.52049 | 3.60526 | 0.99742 | 0.0001668 | 0.0001668 | 0.0001668
2 | 21.216 | 0.72478 | 2.86801 | 1.13424 | 0.02921 | 0.76179 | 0.30305 | 0.25352 | 0.58867 | 3.23644 | 1.02001 | 0.000332445 | 0.000332445 | 0.000332445
3 | 26.3444 | 0.77404 | 2.09831 | 1.16548 | 0.65265 | 0.2456 | 0.34695 | 0.28273 | 0.71099 | 2.78706 | 1.11584 | 0.000491264 | 0.000491264 | 0.000491264
4 | 31.4496 | 0.74546 | 1.65062 | 1.12124 | 0.60633 | 0.48144 | 0.52968 | 0.41193 | 0.675 | 1.77051 | 1.10896 | 0.000522974 | 0.000522974 | 0.000522974
5 | 36.4438 | 0.74081 | 1.51086 | 1.11197 | 0.62274 | 0.55715 | 0.58439 | 0.45504 | 0.64237 | 1.51263 | 1.07714 | 0.000511965 | 0.000511965 | 0.000511965
6 | 41.4337 | 0.68937 | 1.33166 | 1.084 | 0.69936 | 0.47453 | 0.54934 | 0.43043 | 0.66841 | 1.80349 | 1.09496 | 0.000500956 | 0.000500956 | 0.000500956
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

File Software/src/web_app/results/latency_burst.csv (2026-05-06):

seq | event_id | quest_send_ms | response_latency_ms | reported_latency_ms | status
0 | quest_evt_000000 | 1777521968531.001 | 2.45 | 1.79 | ok
1 | quest_evt_000001 | 1777521968533.483 | 1.31 | 0.87 | ok
2 | quest_evt_000002 | 1777521968631.034 | 1.69 | 1.15 | ok
3 | quest_evt_000003 | 1777521968731.085 | 4.21 | 2.6 | ok
4 | quest_evt_000004 | 1777521968831.139 | 1.73 | 1.06 | ok
5 | quest_evt_000005 | 1777521968931.177 | 2.16 | 1.33 | ok
6 | quest_evt_000006 | 1777521969031.2 | 2.76 | 1.66 | ok
7 | quest_evt_000007 | 1777521969131.072 | 3.26 | 2.04 | ok
8 | quest_evt_000008 | 1777521969231.147 | 1.75 | 1.11 | ok
9 | quest_evt_000009 | 1777521969331.076 | 1.82 | 1.22 | ok
10 | quest_evt_000010 | 1777521969431.063 | 1.67 | 1.02 | ok
11 | quest_evt_000011 | 1777521969531.171 | 1.72 | 1.08 | ok
12 | quest_evt_000012 | 1777521969631.112 | 1.7 | 1.14 | ok
13 | quest_evt_000013 | 1777521969731.192 | 4.18 | 2.64 | ok
14 | quest_evt_000014 | 1777521969831.211 | 1.75 | 1.13 | ok
15 | quest_evt_000015 | 1777521969931.16 | 1.68 | 1.06 | ok
16 | quest_evt_000016 | 1777521970031.05 | 3.26 | 1.92 | ok
17 | quest_evt_000017 | 1777521970131.074 | 4.72 | 3.17 | ok
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

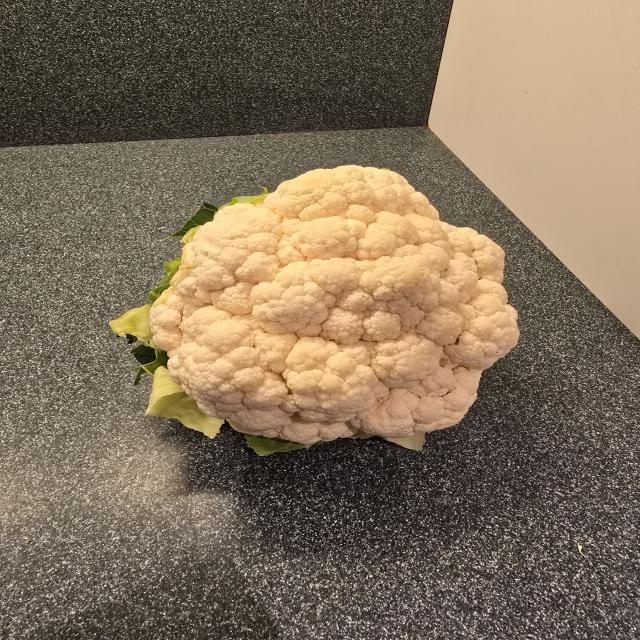
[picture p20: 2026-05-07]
Software/src/NuChef_Vision/filtered_dataset_core/test/images/20250528_001000_jpg.rf.dbc16f1b9cdcafb79112004c8eec087f.jpg

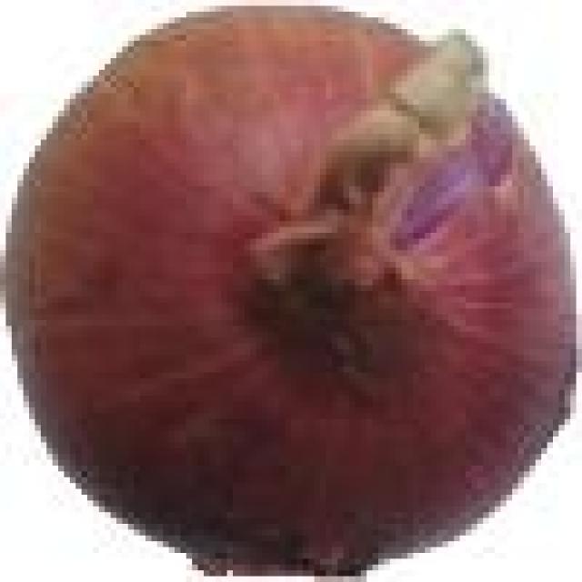
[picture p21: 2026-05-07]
Software/src/NuChef_Vision/filtered_dataset_core/test/images/onion_normal-105-_jpg.rf.7e5feb3831025eca1bdab7eeee3956f4.jpg

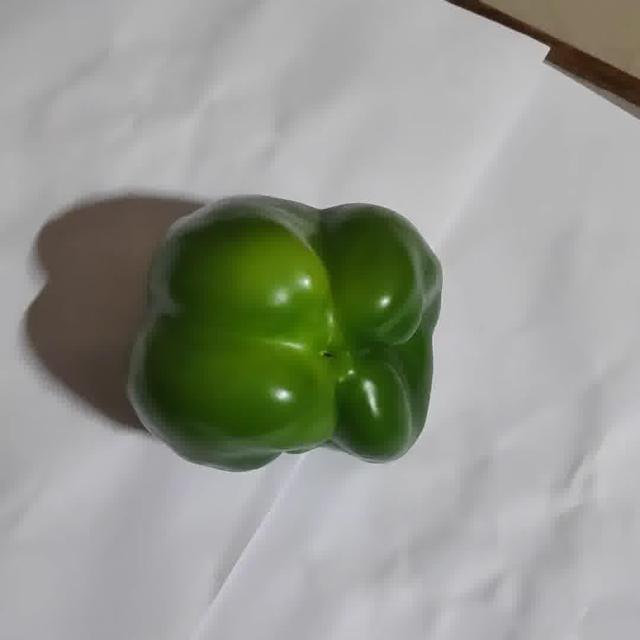
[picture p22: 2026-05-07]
Software/src/NuChef_Vision/filtered_dataset_core/test/images/capsicum_green-1015-_jpg.rf.b58d245c71d5981e8b880225f8d5b16f.jpg

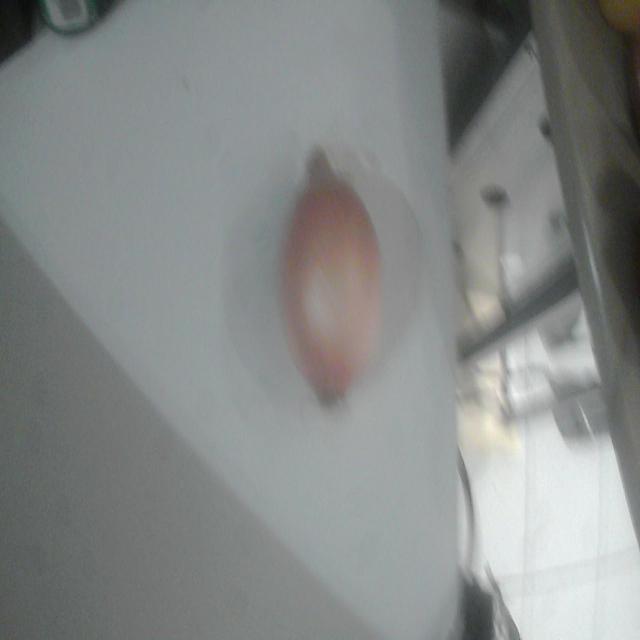
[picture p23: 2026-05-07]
Software/src/NuChef_Vision/filtered_dataset_core/test/images/WIN_20250619_00_42_16_Pro_jpg.rf.31df79387f0a7777c0ceee3e495865cf.jpg

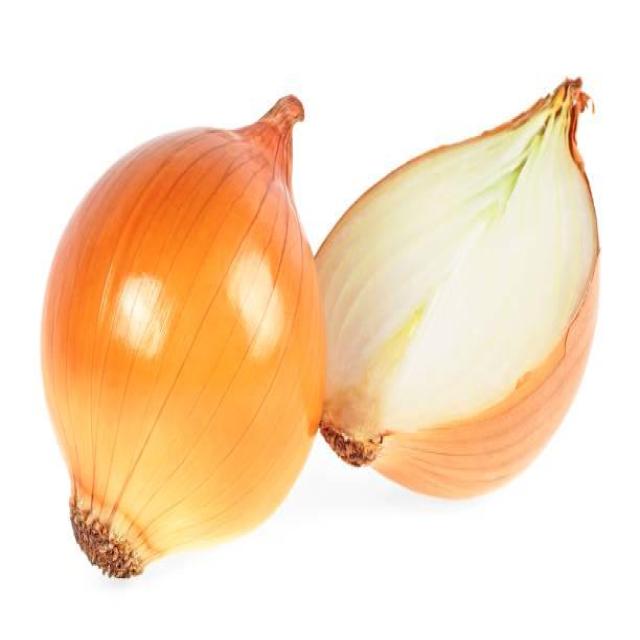
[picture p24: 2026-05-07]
Software/src/NuChef_Vision/filtered_dataset_core/test/images/istockphoto-938439090-612x612_jpg.rf.dbe505d4309707402fd223469bc524b9.jpg

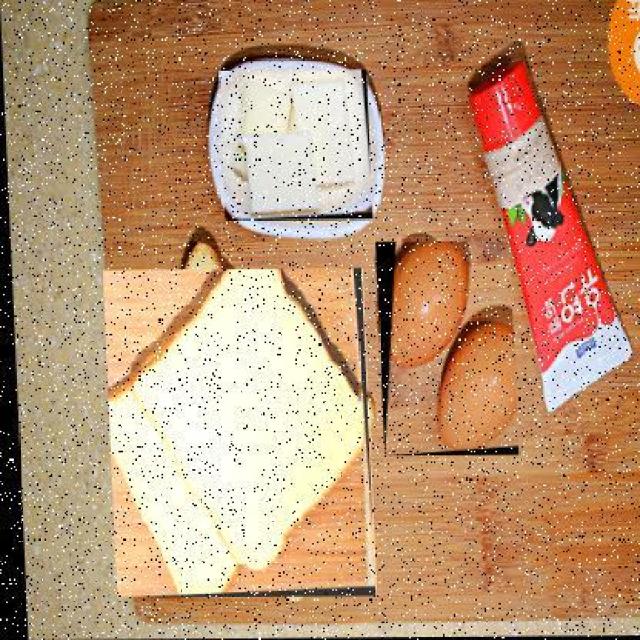
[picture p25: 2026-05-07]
Software/src/NuChef_Vision/filtered_dataset_core/test/images/041_PNG_jpg.rf.7dc4d58422360d9f218b92748741da89.jpg

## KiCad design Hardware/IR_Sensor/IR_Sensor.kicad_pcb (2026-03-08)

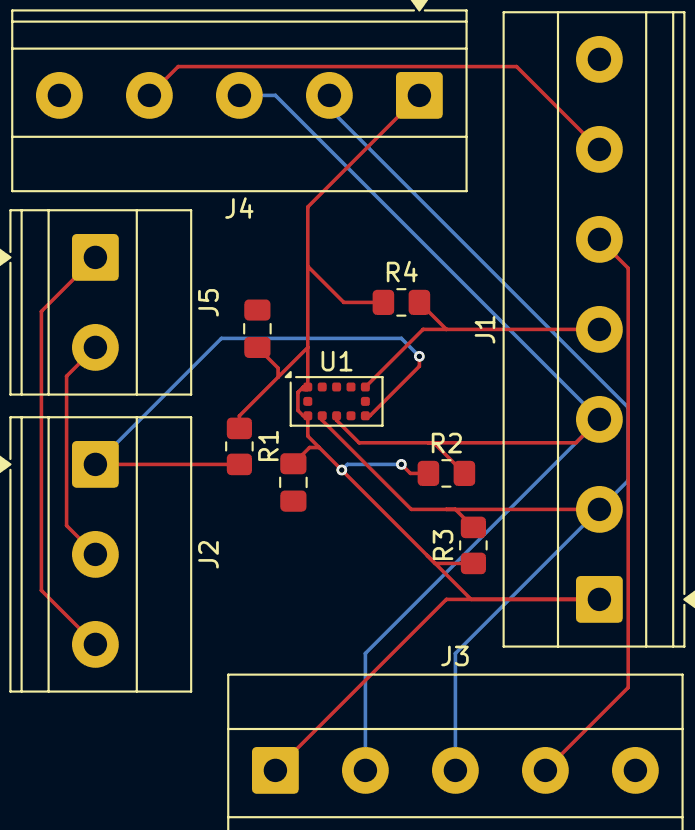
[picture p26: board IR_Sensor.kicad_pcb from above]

Board: 2 copper layers, 12 parts (0 on the bottom side), 10 nets.

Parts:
C1: 100nF; C_0805_2012Metric_Pad1.18x1.45mm_HandSolder
C2: 4.7uF; C_0805_2012Metric_Pad1.18x1.45mm_HandSolder
J1: Conn_01x07_Pin; TerminalBlock_Phoenix_MKDS-1,5-7_1x07_P5.00mm_Horizontal
J2: Conn_01x03_Pin; TerminalBlock_Phoenix_MKDS-1,5-3_1x03_P5.00mm_Horizontal
J3, J4: Conn_01x05_Pin; TerminalBlock_Phoenix_MKDS-1,5-5_1x05_P5.00mm_Horizontal
J5: Conn_01x02_Pin; TerminalBlock_Phoenix_MKDS-1,5-2_1x02_P5.00mm_Horizontal
R1, R2, R3, R4: 4.7k; R_0805_2012Metric_Pad1.20x1.40mm_HandSolder
U1: VL53L0CXV0DH1; ST_VL53L1x

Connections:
+3.3V: C1.1, C2.1, J1.1, J3.1, J4.1, R1.1, R2.1, R3.1, R4.1, U1.1 (AVDDVCSEL), U1.11 (AVDD)
/GPIO1_1: J2.1, R1.2, U1.7 (GPIO1)
/GPIO1_2: J2.2, J5.2
/GPIO1_3: J2.3, J5.1
/SCL: J1.2, J3.3, J4.2, R3.2, U1.10 (SCL)
/SDA: J1.3, J3.2, J4.3, R2.2, U1.9 (SDA)
/XSHUT1: J1.4, R4.2, U1.5 (XSHUT)
/XSHUT2: J1.5, J3.4
/XSHUT3: J1.6, J4.4
GND: C1.2, C2.2, J1.7, J3.5, J4.5, U1.2 (AVSSVCSEL), U1.3 (GND), U1.4 (GND), U1.6 (GND), U1.12 (GND)

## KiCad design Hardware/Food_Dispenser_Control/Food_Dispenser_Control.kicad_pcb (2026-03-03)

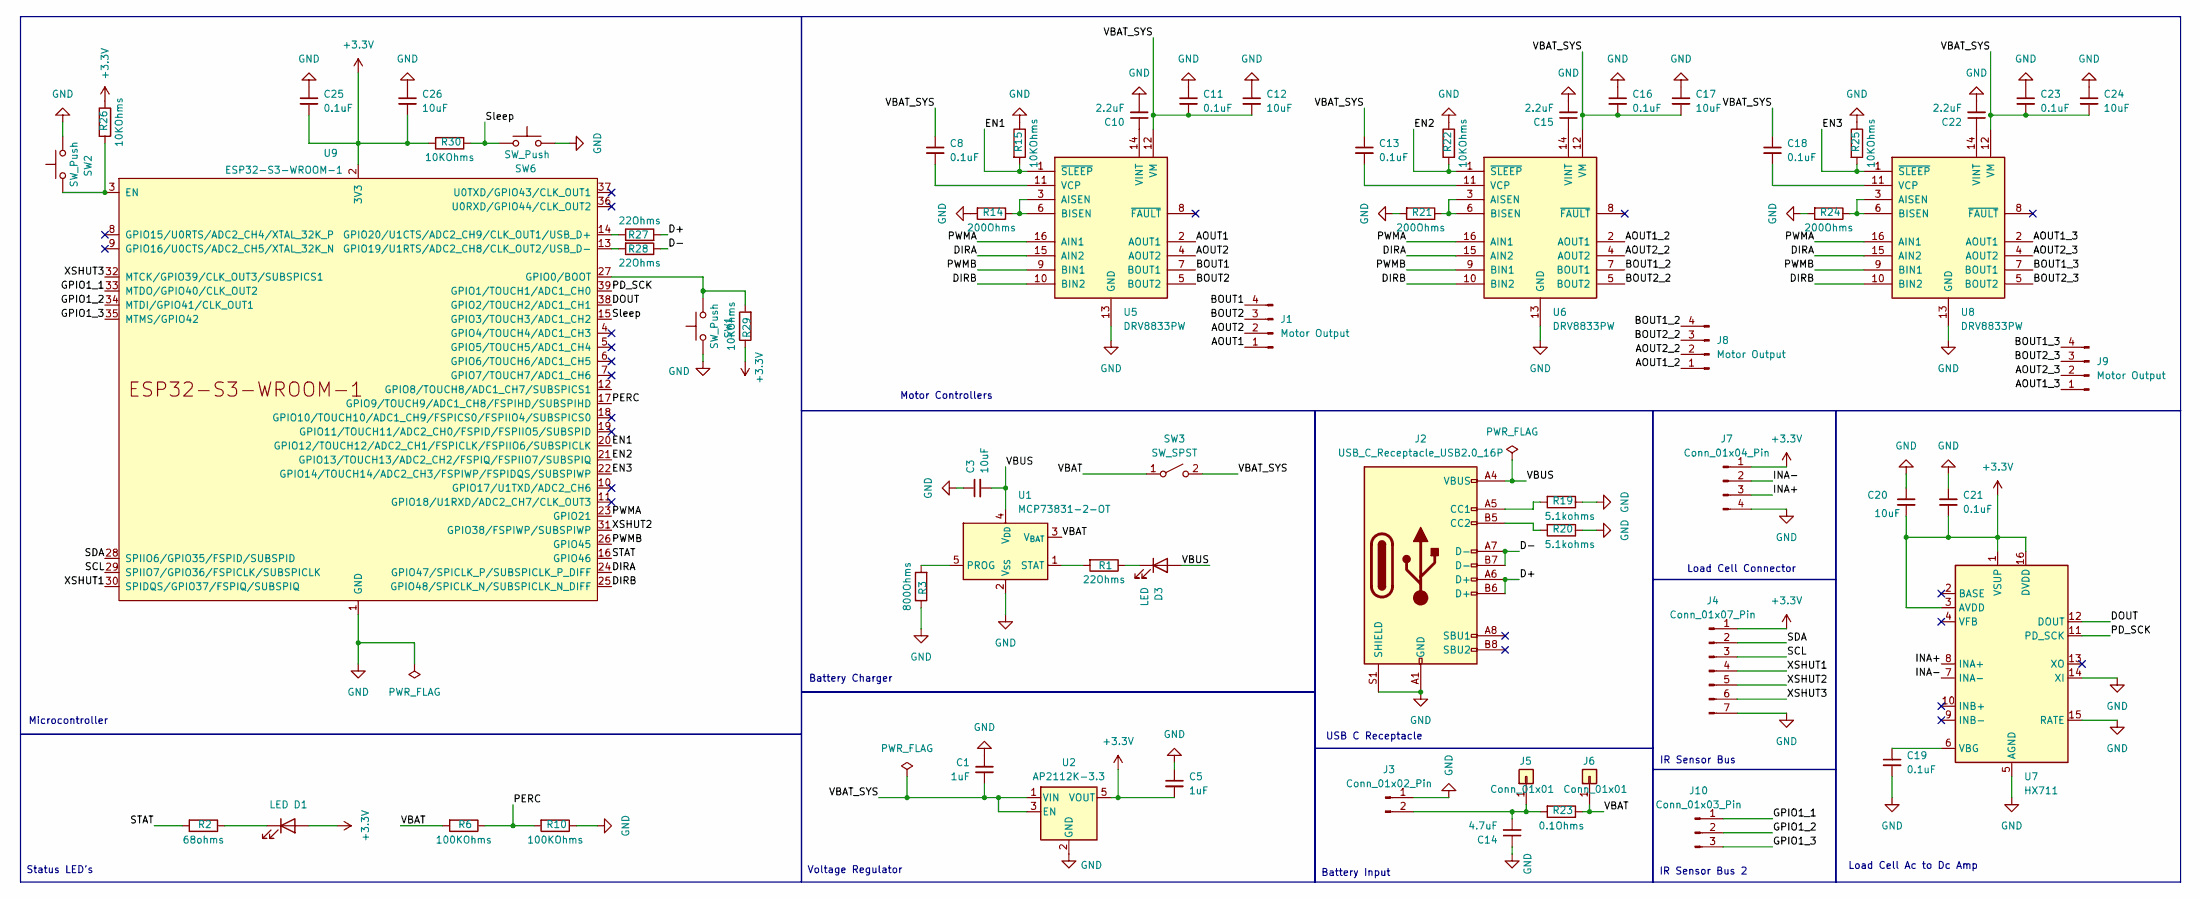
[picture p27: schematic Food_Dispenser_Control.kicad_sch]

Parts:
C1, C5: 1uF; C_0805_2012Metric_Pad1.18x1.45mm_HandSolder
C3, C12, C17, C20, C24, C26: 10uF; C_0805_2012Metric_Pad1.18x1.45mm_HandSolder
C8, C11, C13, C16, C18, C19, C21, C23, C25: 0.1uF; C_0805_2012Metric_Pad1.18x1.45mm_HandSolder
C10, C15, C22: 2.2uF; C_0805_2012Metric_Pad1.18x1.45mm_HandSolder
C14: 4.7uF; C_0805_2012Metric_Pad1.18x1.45mm_HandSolder
D1, D3: LED; LED_0805_2012Metric_Pad1.15x1.40mm_HandSolder
J1, J8, J9: Motor Output; TerminalBlock_Phoenix_MKDS-1,5-4_1x04_P5.00mm_Horizontal
J2: USB_C_Receptacle_USB2.0_16P; USB_C_Receptacle_GCT_USB4105-xx-A_16P_TopMnt_Horizontal
J3: Conn_01x02_Pin; TerminalBlock_Phoenix_MKDS-1,5-2_1x02_P5.00mm_Horizontal
J4: Conn_01x07_Pin; TerminalBlock_Phoenix_MKDS-1,5-7_1x07_P5.00mm_Horizontal
J5, J6: Conn_01x01; TestPoint_Pad_D1.5mm
J7: Conn_01x04_Pin; TerminalBlock_Phoenix_MKDS-1,5-4_1x04_P5.00mm_Horizontal
J10: Conn_01x03_Pin; TerminalBlock_Phoenix_MKDS-1,5-3_1x03_P5.00mm_Horizontal
R1, R27, R28: 22Ohms; R_0805_2012Metric_Pad1.20x1.40mm_HandSolder
R2: 68ohms; R_0805_2012Metric_Pad1.20x1.40mm_HandSolder
R3: 800Ohms; R_0805_2012Metric_Pad1.20x1.40mm_HandSolder
R6, R10: 100KOhms; R_0805_2012Metric_Pad1.20x1.40mm_HandSolder
R14, R21, R24: 200Ohms; R_0805_2012Metric_Pad1.20x1.40mm_HandSolder
R15, R22, R25, R26, R29, R30: 10KOhms; R_0805_2012Metric_Pad1.20x1.40mm_HandSolder
R19, R20: 5.1kohms; R_0805_2012Metric_Pad1.20x1.40mm_HandSolder
R23: 0.1Ohms; R_0805_2012Metric_Pad1.20x1.40mm_HandSolder
SW1, SW2, SW6: SW_Push; SW_PUSH_6mm_H5mm
SW3: SW_SPST; SW_DIP_SPSTx01_Slide_6.7x4.1mm_W7.62mm_P2.54mm_LowProfile
U1: MCP73831-2-OT; SOT-23-5
U2: AP2112K-3.3; SOT-23-5
U5, U6, U8: DRV8833PW; TSSOP-16_4.4x5mm_P0.65mm
U7: HX711; SOP-16_3.9x9.9mm_P1.27mm
U9: ESP32-S3-WROOM-1

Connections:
+3.3V: C5.2, C20.2, C21.2, C25.2, C26.2, D1.2 (A), J4.1, J7.1, R26.1, R29.1, R30.2, U2.5 (VOUT), U7.1 (VSUP), U7.3 (AVDD), U7.16 (DVDD), U9.2 (3V3)
/AOUT1: J1.1, U5.2 (AOUT1)
/AOUT1_2: J8.1, U6.2 (AOUT1)
/AOUT1_3: J9.1, U8.2 (AOUT1)
/AOUT2: J1.2, U5.4 (AOUT2)
/AOUT2_2: J8.2, U6.4 (AOUT2)
/AOUT2_3: J9.2, U8.4 (AOUT2)
/BOUT1: J1.4, U5.7 (BOUT1)
/BOUT1_2: J8.4, U6.7 (BOUT1)
/BOUT1_3: J9.4, U8.7 (BOUT1)
/BOUT2: J1.3, U5.5 (BOUT2)
/BOUT2_2: J8.3, U6.5 (BOUT2)
/BOUT2_3: J9.3, U8.5 (BOUT2)
/D+: J2.A6 (D+), J2.B6 (D+), R27.2
/D-: J2.A7 (D-), J2.B7 (D-), R28.1
/DIRA: U5.15 (AIN2), U6.15 (AIN2), U8.15 (AIN2), U9.24 (GPIO47/SPICLK_P/SUBSPICLK_P_DIFF)
/DIRB: U5.10 (BIN2), U6.10 (BIN2), U8.10 (BIN2), U9.25 (GPIO48/SPICLK_N/SUBSPICLK_N_DIFF)
/DOUT: U7.12 (DOUT), U9.38 (GPIO2/TOUCH2/ADC1_CH1)
/EN1: R15.2, U5.1 (~SLEEP), U9.20 (GPIO12/TOUCH12/ADC2_CH1/FSPICLK/FSPIIO6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)
/EN2: R22.2, U6.1 (~SLEEP), U9.21 (GPIO13/TOUCH13/ADC2_CH2/FSPIQ/FSPIIO7/S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)
/EN3: R25.2, U8.1 (~SLEEP), U9.22 (GPIO14/TOUCH14/ADC2_CH3/FSPIWP/FSPIDQS/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)
/GPIO1_1: J10.1, U9.33 (MTDO/GPIO40/CLK_OUT2)
/GPIO1_2: J10.2, U9.34 (MTDI/GPIO41/CLK_OUT1)
/GPIO1_3: J10.3, U9.35 (MTMS/GPIO42)
/INA+: J7.3, U7.8 (INA+)
/INA-: J7.2, U7.7 (INA-)
/PD_SCK: U7.11 (PD_SCK), U9.39 (GPIO1/TOUCH1/ADC1_CH0)
/PERC: R6.1, R10.2, U9.17 (GPIO9/TOUCH9/ADC1_CH8/FSPIHD/SUBSPIHD)
/PWMA: U5.16 (AIN1), U6.16 (AIN1), U8.16 (AIN1), U9.23 (GPIO21)
/PWMB: U5.9 (BIN1), U6.9 (BIN1), U8.9 (BIN1), U9.26 (GPIO45)
/SCL: J4.3, U9.29 (SPIIO7/GPIO36/FSPICLK/SUBSPICLK)
/SDA: J4.2, U9.28 (SPIIO6/GPIO35/FSPID/SUBSPID)
/STAT: R2.2, U9.16 (GPIO46)
/Sleep: R30.1, SW6.1, U9.15 (GPIO3/TOUCH3/ADC1_CH2)
/VBAT: J6.1, R6.2, R23.1, SW3.1 (A), U1.3 (V_{BAT})
/VBAT_SYS: C1.2, C8.1, C11.2, C12.2, C13.1, C16.2, C17.2, C18.1, C23.2, C24.2, SW3.2 (B), U2.1 (VIN), U2.3 (EN), U5.12 (VM), U6.12 (VM), U8.12 (VM)
/VBUS: C3.2, D3.2 (A), J2.A4 (VBUS), J2.A9 (VBUS), J2.B4 (VBUS), J2.B9 (VBUS), U1.4 (V_{DD})
/XSHUT1: J4.4, U9.30 (SPIDQS/GPIO37/FSPIQ/SUBSPIQ)
/XSHUT2: J4.5, U9.31 (GPIO38/FSPIWP/SUBSPIWP)
/XSHUT3: J4.6, U9.32 (MTCK/GPIO39/CLK_OUT3/SUBSPICS1)
GND: C1.1, C3.1, C5.1, C10.2, C11.1, C12.1, C14.1, C15.2, C16.1, C17.1, C19.2, C20.1, C21.1, C22.2, C23.1, C24.1, C25.1, C26.1, J2.A1 (GND), J2.A12 (GND), J2.B1 (GND), J2.B12 (GND), J2.S1 (SHIELD), J3.1, J4.7, J7.4, R3.1, R10.1, R14.2, R15.1, R19.1, R20.1, R21.2, R22.1, R24.2, R25.1, SW1.1, SW2.2, SW6.2, U1.2 (V_{SS}), U2.2 (GND), U5.13 (GND), U6.13 (GND), U7.5 (AGND), U7.14 (XI), U7.15 (RATE), U8.13 (GND), U9.1 (GND), U9.40 (GND), U9.41 (GND)
unnamed: D1.1 (K), R2.1
unnamed: D3.1 (K), R1.1
unnamed: J2.A5 (CC1), R19.2
unnamed: J2.B5 (CC2), R20.2
unnamed: C14.2, J3.2, J5.1, R23.2
unnamed: R3.2, U1.5 (PROG)
unnamed: R1.2, U1.1 (STAT)
unnamed: R14.1, U5.3 (AISEN), U5.6 (BISEN)
unnamed: C8.2, U5.11 (VCP)
unnamed: C10.1, U5.14 (VINT)
unnamed: R21.1, U6.3 (AISEN), U6.6 (BISEN)
unnamed: C13.2, U6.11 (VCP)
unnamed: C15.1, U6.14 (VINT)
unnamed: C19.1, U7.6 (VBG)
unnamed: R24.1, U8.3 (AISEN), U8.6 (BISEN)
unnamed: C18.2, U8.11 (VCP)
unnamed: C22.1, U8.14 (VINT)
unnamed: R26.2, SW2.1, U9.3 (EN)
unnamed: R29.2, SW1.2, U9.27 (GPIO0/BOOT)
unnamed: R28.2, U9.13 (GPIO19/U1RTS/ADC2_CH8/CLK_OUT2/USB_D-)
unnamed: R27.1, U9.14 (GPIO20/U1CTS/ADC2_CH9/CLK_OUT1/USB_D+)

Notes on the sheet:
IR Sensor Bus 2
Status LED's
IR Sensor Bus
Load Cell Connector
Motor Controllers
Microcontroller
Battery Input
Battery Charger
USB C Receptacle
Load Cell Ac to Dc Amp
Voltage Regulator

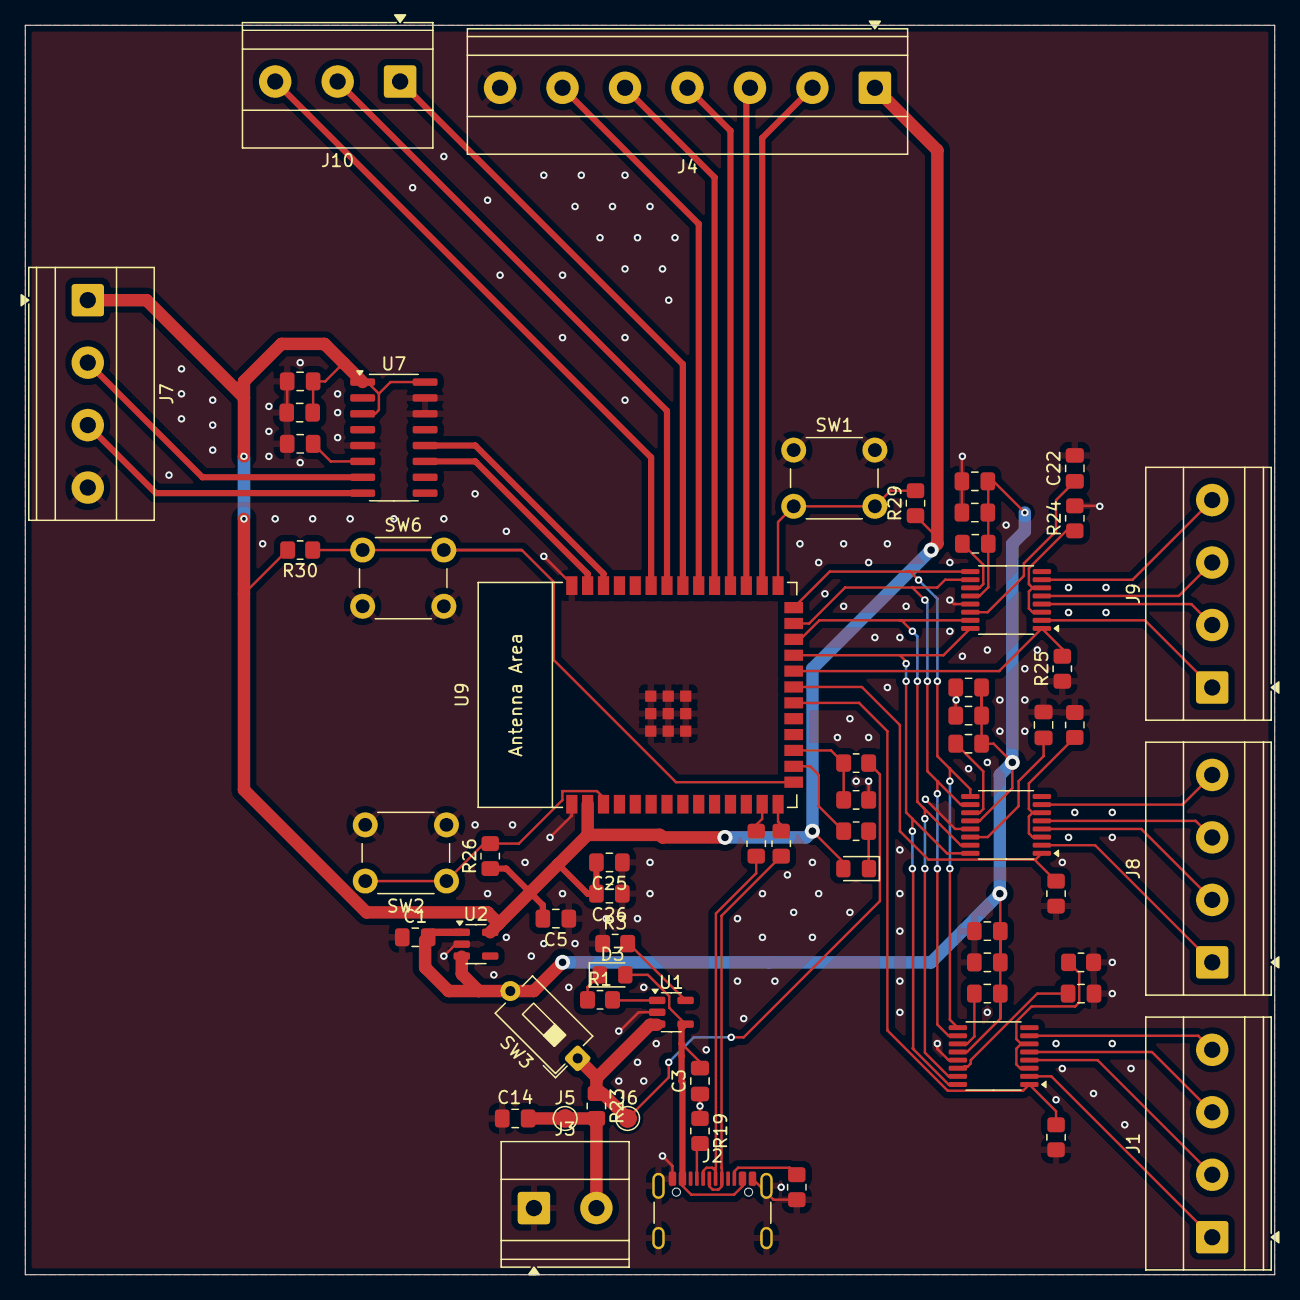
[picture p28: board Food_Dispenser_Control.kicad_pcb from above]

Board: 2 copper layers, 100.0 x 100.0 mm, 63 parts (0 on the bottom side), 62 nets.

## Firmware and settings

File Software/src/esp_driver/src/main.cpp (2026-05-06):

// AI Nutritious Culinary Assistant — ESP32-S3 Dispenser Firmware (BLE)
// TB6612 motor driver, FULL4WIRE steppers, BLE communication.
// HX711 load cell on pins DOUT=2, SCK=1 for real-time weight.
//
// BLE Protocol:
//   Advertises as "NuChef-Dispenser" with a custom GATT service.
//   A BLE central (ble_bridge.py on the backend machine) connects and
//   communicates via three characteristics:
//
//     CMD_CHAR  (write):  receives dispense commands
//       → {"action":"dispense","command_id":"...","container_index":0,"target_grams":2.5}
//     RSLT_CHAR (notify): sends command results
//       → {"command_id":"...","status":"done","actual_grams":2.5,"weight":0}
//     WT_CHAR   (notify): sends periodic weight heartbeats
//       → {"weight":0}
//
// Wiring summary  (TB6612 → ESP32-S3):
//   All three motors share the 4 coil-drive pins below.
//   The active motor is selected by its ENABLE line.
//   container_index 0 → Left motor
//   container_index 1 → Middle motor
//   container_index 2 → Right motor
//
// Calibration:
//   STEPS_PER_GRAM — motor steps per gram dispensed (measure empirically)

#include <Arduino.h>
#include <AccelStepper.h>
#include <BLEDevice.h>
#include <BLEServer.h>
#include <BLEUtils.h>
#include <BLE2902.h>
#include <ArduinoJson.h>
#include "HX711.h"
#include <Wire.h>
#include "Adafruit_VL53L0X.h"

// ── BLE UUIDs ─────────────────────────────────────────────────────────────────

#define SERVICE_UUID   "4e7a9b1c-d203-4e2a-b8f1-67c1d9e3f5a0"
#define CMD_CHAR_UUID  "4e7a9b1c-d203-4e2a-b8f1-67c1d9e3f5a1" // Write
#define RSLT_CHAR_UUID "4e7a9b1c-d203-4e2a-b8f1-67c1d9e3f5a2" // Notify
#define WT_CHAR_UUID   "4e7a9b1c-d203-4e2a-b8f1-67c1d9e3f5a3" // Notify

const char *BLE_DEVICE_NAME = "NuChef-Dispenser";

// ── Load cell (HX711) ──────────────────────────────────────────────────────────

const int LOADCELL_DOUT_PIN = 2;
const int LOADCELL_SCK_PIN  = 1;
const float HX711_SCALE_FACTOR = float(1250.0f);  // (raw reading) / actual grams — calibrated 2026-04-29
const float WEIGHT_ZERO_THRESHOLD = 0.05f; // readings below this → 0
const unsigned long HX711_READY_TIMEOUT_MS = 3000;

HX711 scale;
bool  scaleReady = false;   // set true only if tare succeeds
float currentWeight = 0.0f; // latest reading in grams

// ── BLE state ─────────────────────────────────────────────────────────────────

BLEServer         *pServer   = nullptr;
BLECharacteristic *pCmdChar  = nullptr;
BLECharacteristic *pRsltChar = nullptr;
BLECharacteristic *pWtChar   = nullptr;

bool deviceConnected    = false;
bool oldDeviceConnected = false;

// Command buffer — written by the BLE callback, consumed in loop()
volatile bool commandReady = false;
String  pendingCmdId;
int     pendingContainerIdx = -1;
float   pendingTargetGrams  = 0.0f;

// Calibration step command
volatile bool calibStepReady = false;
String calibStepCmdId;
int    calibMotorIdx = -1;
long   calibSteps    = 0;

// Reset-position command
volatile bool calibResetReady = false;
String calibResetCmdId;

// ── Timing ────────────────────────────────────────────────────────────────────

const unsigned long HEARTBEAT_MS    = 2000;  // ms between weight notifications
const unsigned long IR_HEARTBEAT_MS = 5000;  // ms between IR sensor sweeps
unsigned long lastHeartbeat   = 0;
unsigned long lastIrRead      = 0;
bool dispensing = false;

// ── IR distance sensors (VL53L0X × 3, one shared object, time-multiplexed I2C) ─
// Left  → chili pepper  (SDA=35, SCL=36, empty=90mm, full=45mm)
// Middle → MSG          (SDA=38, SCL=37, empty=111mm, full=80mm)
// Right  → salt         (SDA=40, SCL=39, empty=90mm,  full=32mm)

struct IrSensorConfig {
  const char* name;
  int         sda;
  int         scl;
  float       emptyMm;  // distance when container is empty
  float       fullMm;   // distance when container is full
};

const IrSensorConfig IR_SENSORS[3] = {
  {"left",   35, 36, 145.0f, 48.0f},   // chili pepper
  {"middle", 38, 37, 134.0f, 42.0f},  // MSG (calibrated: 109.2mm→80%)
  {"right",  40, 39,  144.0f,  45.0f},  // salt (calibrated: 66.2mm→85%)
};

Adafruit_VL53L0X irLox;   // single shared object — re-init each sensor
int irLevels[3] = {-1, -1, -1};  // fill % (0-100), -1 = not yet read

// Read one VL53L0X by switching the I2C bus to its pins.
// Returns fill percentage 0-100, or -1 on failure.
int readIrSensor(const IrSensorConfig& s)
{
  Wire.end();
  delay(5);
  Wire.begin(s.sda, s.scl);
  Wire.setClock(100000);
  delay(5);

  if (!irLox.begin(0x29, false, &Wire)) {
    Serial.printf("IR[%s]: VL53L0X init failed\n", s.name);
    return -1;
  }

  const int SAMPLES   = 12;
  const int MIN_VALID = 4;  // need at least this many good samples
  float sum   = 0.0f;
  int   valid = 0;

  for (int i = 0; i < SAMPLES; i++) {
    VL53L0X_RangingMeasurementData_t m;
    irLox.rangingTest(&m, false);
    if (m.RangeStatus != 4) {   // 4 = out-of-range
      sum += m.RangeMilliMeter;
      valid++;
    }
    delay(5);
  }

  if (valid < MIN_VALID) {
    Serial.printf("IR[%s]: too many OOR readings\n", s.name);
    return -1;
  }

  float reading = sum / valid;
  float range   = s.fullMm - s.emptyMm;
  float pct     = (range != 0.0f) ? (reading - s.emptyMm) / range : 0.0f;
  // Clamp and snap near edges
  if (pct <= 0.05f) pct = 0.0f;
  if (pct >= 0.95f) pct = 1.0f;
  int level = (int)(pct * 100.0f + 0.5f);
  level = max(0, min(100, level));

  Serial.printf("IR[%s]: %.1fmm → %d%%\n", s.name, reading, level);
  return level;
}

void readAllIrSensors()
{
  for (int i = 0; i < 3; i++) {
    int lvl = readIrSensor(IR_SENSORS[i]);
    if (lvl >= 0) irLevels[i] = lvl;  // keep previous value on failure
  }

  // Print all spice levels together in backend container order.
  // container 0 = salt (right sensor), 1 = msg (middle), 2 = chili pepper (left)
  Serial.printf("Spice levels -> salt:%d%%  msg:%d%%  chili:%d%%\n",
                irLevels[2], irLevels[1], irLevels[0]);
}

// ── Motors — TB6612 FULL4WIRE steppers ────────────────────────────────────────
// All three spice augers share the same 4 phase lines.
// We select Left / Middle / Right with the dedicated enable pins.

#define AIN1R 21
#define AIN2R 47
#define BIN1R 45
#define BIN2R 48
#define ENABLE_R 14

#define ENABLE_M 13
#define ENABLE_L 12

enum MotorSlot : int
{
  MOTOR_LEFT = 0,
  MOTOR_MIDDLE = 1,
  MOTOR_RIGHT = 2,
};

const int MOTOR_ENABLE_PINS[3] = {ENABLE_L, ENABLE_M, ENABLE_R};
const char *MOTOR_SLOT_NAMES[3] = {"left", "middle", "right"};

AccelStepper dispenseMotor(AccelStepper::FULL4WIRE, AIN1R, AIN2R, BIN1R, BIN2R);

// ── Per-motor calibration: measured grams dispensed per one rotation cycle ────
const float GRAMS_PER_ROTATION[3] = {1.1f, 0.7f, 0.27f};  // salt, msg, chili pepper

const float MOTOR_MAX_SPEED    = 800.0f;  // from motor_test.cpp
const float MOTOR_ACCELERATION = 200.0f;  // from motor_test.cpp
const float STEPS_PER_GRAM     = 320.0f;          // CALIBRATE: steps / gram
const unsigned long DISPENSE_TIMEOUT_MS = 30000;   // 30 s hard timeout (covers multi-cycle)

// ── Per-motor two-part cycle calibration ─────────────────────────────────────
// Motors are manually calibrated to their zero (closed) position first.
// Each dispense cycle rotates 180° forward then returns to 0°.
// 200 full steps = 360° → 100 steps = 180°
const long STEPS_180 = 100;   // forward leg: 0° → 180°
                               // back leg:    180° → 0°  (same count, reverse dir)
const unsigned long CYCLE_PAUSE_MS = 500;  // pause between forward and back leg


// ── BLE Callbacks ─────────────────────────────────────────────────────────────

class ServerCallbacks : public BLEServerCallbacks
{
  void onConnect(BLEServer *s) override
  {
    deviceConnected = true;
    Serial.println("BLE central connected.");
  }
  void onDisconnect(BLEServer *s) override
  {
    deviceConnected = false;
    Serial.println("BLE central disconnected.");
  }
};

// Called when the central writes a JSON command to CMD_CHAR
class CmdCharCallbacks : public BLECharacteristicCallbacks
{
  void onWrite(BLECharacteristic *pChar) override
  {
    std::string raw = pChar->getValue();
    if (raw.empty()) return;

    Serial.printf("BLE CMD rx: %s\n", raw.c_str());

    JsonDocument doc;
    if (deserializeJson(doc, raw.c_str()))
    {
      Serial.println("  → JSON parse error, ignoring.");
      return;
    }

    const char *action = doc["action"] | "none";

    // ── Tare command — immediate, no queuing ──
    if (strcmp(action, "tare") == 0) {
      if (scaleReady) {
        scale.tare();
        currentWeight = 0.0f;
        Serial.println("HX711: tared via BLE.");
        // Send result back
        if (deviceConnected) {
          JsonDocument rdoc;
          rdoc["command_id"] = doc["command_id"] | "tare";
          rdoc["status"]     = "done";
          rdoc["actual_grams"] = 0;
          rdoc["weight"]     = 0.0f;
          String body;
          serializeJson(rdoc, body);
          pRsltChar->setValue(body.c_str());
          pRsltChar->notify();
        }
      } else {
        Serial.println("HX711: tare requested but scale not ready.");
      }
      return;
    }

    // ── motor_step — calibration nudge ──
    if (strcmp(action, "motor_step") == 0) {
      int  mIdx  = doc["motor"] | -1;
      long steps = doc["steps"] | 0;
      const char *id = doc["command_id"] | "";
      if (mIdx < 0 || mIdx > 2 || steps == 0) return;
      calibStepCmdId = String(id);
      calibMotorIdx  = mIdx;
      calibSteps     = steps;
      calibStepReady = true;
      return;
    }

    // ── motor_reset_position — zero all position counters ──
    if (strcmp(action, "motor_reset_position") == 0) {
      calibResetCmdId  = String(doc["command_id"] | "reset");
      calibResetReady  = true;
      return;
    }

    if (strcmp(action, "dispense") != 0) return;

    const char *id = doc["command_id"] | "";
    if (strlen(id) == 0) return;

    int   idx   = doc["container_index"] | -1;
    float grams = doc["target_grams"]    | 0.0f;
    if (idx < 0 || idx > 2 || grams <= 0.0f) return;

    // Store for loop() to pick up
    pendingCmdId        = String(id);
    pendingContainerIdx = idx;
    pendingTargetGrams  = grams;
    commandReady        = true;
  }
};

// ── BLE notify helpers ────────────────────────────────────────────────────────

void notifyResult(const String &commandId, const char *status,
                  float actualGrams, float weight)
{
  if (!deviceConnected) return;

  JsonDocument doc;
  doc["command_id"]   = commandId;
  doc["status"]       = status;
  doc["actual_grams"] = actualGrams;
  doc["weight"]       = weight;

  String body;
  serializeJson(doc, body);
  pRsltChar->setValue(body.c_str());
  pRsltChar->notify();
  Serial.printf("BLE RSLT tx: %s\n", body.c_str());
}

void notifyWeight(float weight)
{
  if (!deviceConnected) return;

  JsonDocument doc;
  doc["weight"] = weight;

  // Include IR fill levels when available so ble_bridge forwards them
  // to /status_update → container_levels in the web dashboard.
  // Backend CONTAINERS = ["salt", "msg", "chili pepper"] (indices 0,1,2).
  // Physical IR mapping: left(0)=chili pepper, middle(1)=MSG, right(2)=salt.
  // So reorder: container_levels[0]=salt=irLevels[2],
  //             container_levels[1]=MSG=irLevels[1],
  //             container_levels[2]=chili=irLevels[0].
  if (irLevels[0] >= 0 || irLevels[1] >= 0 || irLevels[2] >= 0) {
    auto arr = doc["container_levels"].to<JsonArray>();
    arr.add(irLevels[2] >= 0 ? irLevels[2] : 100);  // salt (right sensor)
    arr.add(irLevels[1] >= 0 ? irLevels[1] : 100);  // MSG  (middle sensor)
    arr.add(irLevels[0] >= 0 ? irLevels[0] : 100);  // chili pepper (left sensor)
  }

  String body;
  serializeJson(doc, body);
  pWtChar->setValue(body.c_str());
  pWtChar->notify();
}

// ── Load cell helpers ─────────────────────────────────────────────────────────

void disableAllMotors()
{
  for (int pin : MOTOR_ENABLE_PINS)
    digitalWrite(pin, LOW);
}

bool selectMotor(int containerIdx)
{
  if (containerIdx < 0 || containerIdx > 2) return false;

  disableAllMotors();
  digitalWrite(MOTOR_ENABLE_PINS[containerIdx], HIGH); // held HIGH for entire dispense
  Serial.printf("Selected %s motor (container %d) — ENABLE HIGH.\n",
                MOTOR_SLOT_NAMES[containerIdx], containerIdx);
  return true;
}

// Non-blocking read — safe to call inside the stepper loop.
// Returns the cached value if the HX711 isn't ready yet.
float readWeight()
{
  if (!scaleReady || !scale.is_ready()) return currentWeight;

  float reading = scale.get_units(3);
  if (fabs(reading) <= WEIGHT_ZERO_THRESHOLD) reading = 0.0f;
  currentWeight = reading;
  return currentWeight;
}

// Blocking read — up to `timeoutMs` ms. Use only when stepping is paused.
float readWeightBlocking(unsigned long timeoutMs = 500)
{
  if (!scaleReady) return currentWeight;
  if (!scale.wait_ready_timeout(timeoutMs, 5)) return currentWeight;
  return readWeight();
}

// ── Dispense ──────────────────────────────────────────────────────────────────

void runDispense(int containerIdx, float targetGrams, const String &commandId)
{
  if (!selectMotor(containerIdx))
  {
    Serial.printf("Invalid container index %d\n", containerIdx);
    notifyResult(commandId, "error", 0.0f, readWeight());
    return;
  }

  Serial.printf("Dispensing %.2fg from %s motor (container %d)\n",
                targetGrams, MOTOR_SLOT_NAMES[containerIdx], containerIdx);

  // Compute how many full rotation cycles cover targetGrams, min 1.
  float gPerRot  = GRAMS_PER_ROTATION[containerIdx];
  int numCycles  = max(1, (int)roundf(targetGrams / gPerRot));
  Serial.printf("Cycle: 0→%ld→0  grams/rot=%.2f  → %d cycle(s) for %.2fg\n",
                STEPS_180, gPerRot, numCycles, targetGrams);

  float weightBefore = readWeightBlocking(500);
  bool timedOut = false;
  unsigned long startMs = millis();

  // Home position is 0 — motor was calibrated here before use.
  dispenseMotor.setCurrentPosition(0);

  for (int cycle = 0; cycle < numCycles && !timedOut; cycle++)
  {
    // ── Leg 1: move to 180° (open) ────────────────────────────────────────
    dispenseMotor.moveTo(STEPS_180);
    while (dispenseMotor.distanceToGo() != 0)
    {
      dispenseMotor.run();
      if (millis() - startMs > DISPENSE_TIMEOUT_MS)
      {
        dispenseMotor.stop();
        timedOut = true;
        Serial.println("Dispense timed out (open leg).");
        break;
      }
    }

    if (timedOut) break;

    // ── Pause at open position ─────────────────────────────────────────────
    delay(CYCLE_PAUSE_MS);

    // ── Leg 2: return to 0° (home/closed) ─────────────────────────────────
    dispenseMotor.moveTo(0);
    while (dispenseMotor.distanceToGo() != 0)
    {
      dispenseMotor.run();
      if (millis() - startMs > DISPENSE_TIMEOUT_MS)
      {
        dispenseMotor.stop();
        timedOut = true;
        Serial.println("Dispense timed out (close leg).");
        break;
      }
    }

    Serial.printf("  cycle %d/%d done\n", cycle + 1, numCycles);
  }

  disableAllMotors();

  // Read final weight from load cell (blocking — motor stopped)
  float weightAfter = readWeightBlocking(500);
  float actualGrams = timedOut ? 0.0f : max(0.0f, weightAfter - weightBefore);
  if (!scaleReady) actualGrams = timedOut ? 0.0f : targetGrams;
  const char *status = timedOut ? "error" : "done";

  Serial.printf("Dispense %s — actual %.2fg, weight %.2fg\n",
                status, actualGrams, weightAfter);

  notifyResult(commandId, status, actualGrams, weightAfter);
}

// ── BLE initialisation ───────────────────────────────────────────────────────

void initBLE()
{
  BLEDevice::init(BLE_DEVICE_NAME);

  pServer = BLEDevice::createServer();
  pServer->setCallbacks(new ServerCallbacks());

  BLEService *pService = pServer->createService(SERVICE_UUID);

  // CMD — central writes dispense commands here
  pCmdChar = pService->createCharacteristic(
      CMD_CHAR_UUID,
      BLECharacteristic::PROPERTY_READ |
      BLECharacteristic::PROPERTY_WRITE);
  pCmdChar->setCallbacks(new CmdCharCallbacks());
  pCmdChar->setValue("ready");

  // RSLT — ESP32 notifies with command results
  pRsltChar = pService->createCharacteristic(
      RSLT_CHAR_UUID,
      BLECharacteristic::PROPERTY_NOTIFY);
  pRsltChar->addDescriptor(new BLE2902());

  // WT — ESP32 notifies with periodic weight
  pWtChar = pService->createCharacteristic(
      WT_CHAR_UUID,
      BLECharacteristic::PROPERTY_NOTIFY);
  pWtChar->addDescriptor(new BLE2902());

  pService->start();

  BLEAdvertising *pAdv = BLEDevice::getAdvertising();
  pAdv->addServiceUUID(SERVICE_UUID);
  pAdv->setScanResponse(true);
  pAdv->start();

  Serial.printf("BLE advertising as \"%s\"\n", BLE_DEVICE_NAME);
}

// ── Setup & loop ──────────────────────────────────────────────────────────────

void setup()
{
  Serial.begin(115200);
  delay(1500); // give USB CDC time to enumerate
  Serial.println("\n=== NuChef Dispenser (BLE) ===");

  pinMode(ENABLE_R, OUTPUT);
  pinMode(ENABLE_M, OUTPUT);
  pinMode(ENABLE_L, OUTPUT);
  disableAllMotors();

  dispenseMotor.setMaxSpeed(MOTOR_MAX_SPEED);
  dispenseMotor.setAcceleration(MOTOR_ACCELERATION);
  Serial.println("Motors configured.");

  // ── HX711 load cell init ───────────────────────────────────────────────────
  pinMode(LOADCELL_SCK_PIN, OUTPUT);
  digitalWrite(LOADCELL_SCK_PIN, LOW);
  scale.begin(LOADCELL_DOUT_PIN, LOADCELL_SCK_PIN);
  if (scale.wait_ready_timeout(HX711_READY_TIMEOUT_MS, 10))
  {
    scale.set_scale(HX711_SCALE_FACTOR);
    scale.tare(10);
    scaleReady = true;
    currentWeight = 0.0f;
    Serial.println("HX711: ready and tared.");
  }
  else
  {
    scaleReady = false;
    Serial.println("HX711: not ready at boot — weight feedback disabled.");
  }

  initBLE();
}

void loop()
{
  unsigned long now = millis();

  // Handle BLE reconnection (restart advertising after disconnect)
  if (!deviceConnected && oldDeviceConnected)
  {
    delay(500); // give the BLE stack time to clean up
    BLEDevice::startAdvertising();
    Serial.println("Restarted BLE advertising.");
    oldDeviceConnected = false;
  }
  if (deviceConnected && !oldDeviceConnected)
  {
    oldDeviceConnected = true;
  }

  // Periodic IR sensor sweep (skipped while dispensing to avoid I2C bus conflicts)
  if (!dispensing && (now - lastIrRead >= IR_HEARTBEAT_MS))
  {
    lastIrRead = now;
    readAllIrSensors();
    
  }

  // Periodic weight heartbeat via BLE notify (includes latest IR levels)
  if (now - lastHeartbeat >= HEARTBEAT_MS)
  {
    lastHeartbeat = now;
    float w = readWeight() * 2.938f;  // convert back to grams for the backend (calibrated: 1g=2.937 raw)
    notifyWeight(w);
  }

  // ── Process calibration step command ─────────────────────────────────────
  if (!dispensing && calibStepReady)
  {
    calibStepReady = false;
    int  mIdx  = calibMotorIdx;
    long steps = calibSteps;
    Serial.printf(">>> Calib step: motor=%d, steps=%ld\n", mIdx, steps);
    selectMotor(mIdx);
    dispenseMotor.setCurrentPosition(0);
    dispenseMotor.moveTo(steps);
    while (dispenseMotor.distanceToGo() != 0)
      dispenseMotor.run();
    while (dispenseMotor.isRunning())
      dispenseMotor.run();
    disableAllMotors();
    Serial.println(">>> Calib step done.");
    // Send result
    if (deviceConnected) {
      notifyResult(calibStepCmdId, "done", 0.0f, currentWeight);
    }
  }

  // ── Process reset-position command ────────────────────────────────────────
  if (!dispensing && calibResetReady)
  {
    calibResetReady = false;
    dispenseMotor.setCurrentPosition(0);
    Serial.println(">>> Motor positions reset to zero.");
    if (deviceConnected) {
      notifyResult(calibResetCmdId, "done", 0.0f, currentWeight);
    }
  }

  // ── Process pending dispense command (skip while a dispense is running) ───
  if (!dispensing && commandReady)
  {
    commandReady = false;
    dispensing   = true;
    Serial.printf(">>> Starting dispense: container=%d, grams=%.2f, id=%s\n",
                  pendingContainerIdx, pendingTargetGrams, pendingCmdId.c_str());
    runDispense(pendingContainerIdx, pendingTargetGrams, pendingCmdId);
    Serial.println(">>> Dispense finished.");
    dispensing   = false;
  }

  // Keep the shared stepper bus ticking if a stop is still decelerating.
  dispenseMotor.run();
}

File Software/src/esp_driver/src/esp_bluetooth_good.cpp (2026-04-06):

// BLE motor control - send "spin" or "stop" from a BLE terminal app

#include <Arduino.h>
#include <AccelStepper.h>
#include <BLEDevice.h>
#include <BLEServer.h>
#include <BLEUtils.h>
#include <BLE2902.h>

#define AIN1R 10
#define AIN2R 11
#define BIN1R 12
#define BIN2R 13

#define AIN1M 10
#define AIN2M 11
#define BIN1M 12
#define BIN2M 13

AccelStepper stepperRight(
  AccelStepper::FULL4WIRE,
  AIN1R, AIN2R, BIN1R, BIN2R
);

AccelStepper stepperMiddle(
    AccelStepper::FULL4WIRE,
    AIN1M, AIN2M, BIN1M, BIN2M
);

// BLE UUIDs
#define SERVICE_UUID        "4fafc201-1fb5-459e-8fcc-c5c9c331914b"
#define CHARACTERISTIC_UUID "beb5483e-36e1-4688-b7f5-ea07361b26a8"

bool motorRunning = false;
bool deviceConnected = false;

class ServerCallbacks : public BLEServerCallbacks {
    void onConnect(BLEServer* pServer) {
        deviceConnected = true;
        Serial.println("BLE client connected");
    }
    void onDisconnect(BLEServer* pServer) {
        deviceConnected = false;
        Serial.println("BLE client disconnected");
        pServer->startAdvertising();
    }
};

class CommandCallbacks : public BLECharacteristicCallbacks {
    void onWrite(BLECharacteristic *pCharacteristic) {
        String value = pCharacteristic->getValue().c_str();
        value.trim();
        value.toLowerCase();
        Serial.print("Received: ");
        Serial.println(value);

        if (value == "spin") {
            motorRunning = true;
            stepperRight.setCurrentPosition(0);
            stepperRight.moveTo(50);
            stepperMiddle.setCurrentPosition(0);
            stepperMiddle.moveTo(50);
            Serial.println("Motors spinning!");
        } else if (value == "stop") {
            motorRunning = false;
            stepperRight.stop();
            stepperMiddle.stop();
            Serial.println("Motors stopped!");
        }
    }
};

void setup()
{
    Serial.begin(115200);
    Serial.println("BLE Motor Control starting...");

    stepperRight.setMaxSpeed(300);
    stepperRight.setAcceleration(100);
    stepperMiddle.setMaxSpeed(300);
    stepperMiddle.setAcceleration(100);

    // Initialize BLE
    BLEDevice::init("NuChef-Motor");
    BLEServer *pServer = BLEDevice::createServer();
    pServer->setCallbacks(new ServerCallbacks());

    BLEService *pService = pServer->createService(SERVICE_UUID);
    BLECharacteristic *pCharacteristic = pService->createCharacteristic(
        CHARACTERISTIC_UUID,
        BLECharacteristic::PROPERTY_READ |
        BLECharacteristic::PROPERTY_WRITE
    );

    pCharacteristic->setCallbacks(new CommandCallbacks());
    pCharacteristic->setValue("ready");
    pService->start();

    BLEAdvertising *pAdvertising = BLEDevice::getAdvertising();
    pAdvertising->addServiceUUID(SERVICE_UUID);
    pAdvertising->setScanResponse(true);
    pAdvertising->start();

    Serial.println("BLE ready! Device name: NuChef-Motor");
    Serial.println("Send 'spin' or 'stop' from a BLE terminal app");
}

void loop()
{
    stepperRight.run();
    stepperMiddle.run();

    if (motorRunning && !stepperRight.isRunning() && !stepperMiddle.isRunning()) {
        stepperRight.moveTo(-stepperRight.currentPosition());
        stepperMiddle.moveTo(-stepperMiddle.currentPosition());
    }
}

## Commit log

2026-02-25 Da Board
    [Food_Dispenser_Control.kicad_pcb, Food_Dispenser_Control.kicad_sch]
2026-02-25 IR sensor board
    [IR_Sensor.kicad_pcb, IR_Sensor.kicad_sch]
2026-02-25 s3 migration
    [Food_Dispenser_Control.kicad_sch]
2026-02-26 schematic and footprints
    [Food_Dispenser_Control.kicad_sch]
2026-02-28 Some stuff idk
    [Food_Dispenser_Control.kicad_sch]
2026-03-03 Ground Plane
    [Food_Dispenser_Control.kicad_pcb]
2026-03-03 Ground routing
    [Food_Dispenser_Control.kicad_pcb]
2026-03-04 IR Main Board
    [IR_Sensor.kicad_pcb, IR_Sensor.kicad_sch]
2026-03-08 Motor driver code, 1st draft, breadboard demo
2026-03-10 Added WiFi Capabilities to comm w/ the ESP32
2026-04-06 Motor Integration Successful
2026-04-21 Apr.21st testing on PCB
2026-05-07 Renamed Notebook and Organized Materials
2026-05-07 Griffin & Jackson ready for updating notebook
    [performance_table.csv, results.csv]
2026-05-08 Rename Screenshot 2026-05-07 220428.png to voltage_reg_V1
2026-05-08 Rename Screenshot 2026-05-07 222739.png to schematic
2026-05-08 Rename Battery Perf.png to Battery_Perf.png
